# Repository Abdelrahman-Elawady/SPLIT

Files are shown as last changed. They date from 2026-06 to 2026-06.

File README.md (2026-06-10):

<div align="center">
  
# 🤖 Project S.P.L.I.T.
**Snapping Pendulums Literally In Two**






*A highly advanced, self-balancing robotic swarm architecture utilizing distributed Dual-MCU processing, cascaded PID control, and computer vision for high-density indoor micro-logistics.*

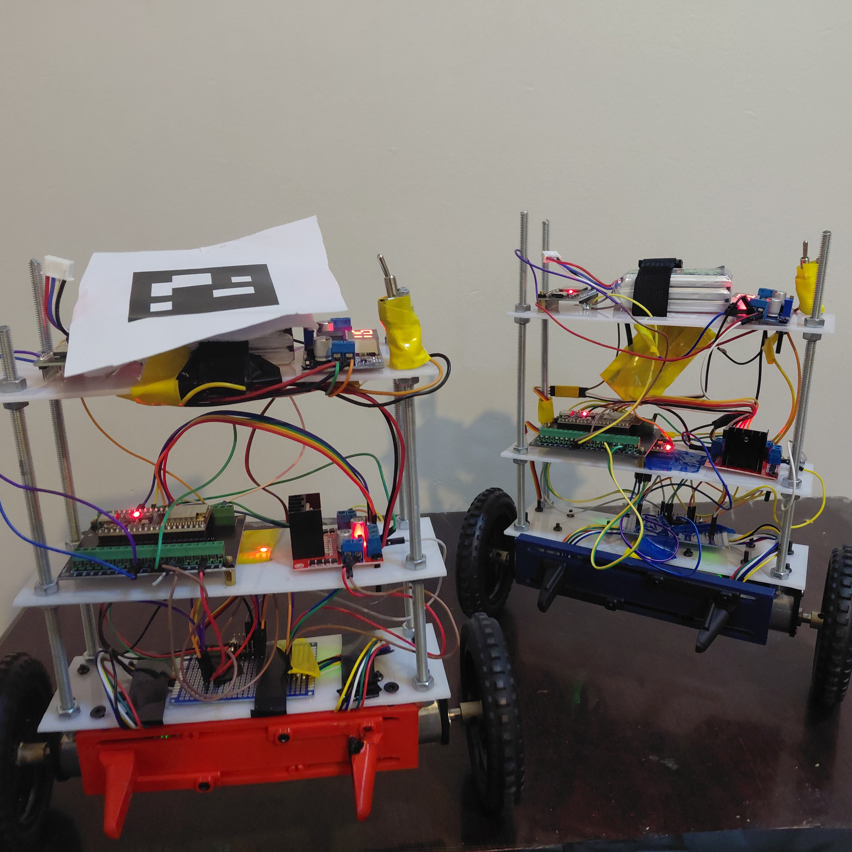
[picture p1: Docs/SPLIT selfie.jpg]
S.P.L.I.T. Swarm


**[🎥 Watch the Project Trailer on YouTube](https://youtu.be/ys7Rda4Vqj8?si=qLUs55d14E2go74t)**

</div>

---

## 📖 Table of Contents
1. [About the Project](#-about-the-project)
2. [Swarm Demonstration](#-swarm-demonstration)
3. [Distributed Hardware Architecture](#-distributed-hardware-architecture-dual-mcu)
4. [Control Theory & Physics](#-control-theory--physics)
5. [Real-Time Telemetry Dashboard](#-real-time-telemetry-dashboard)
6. [Computer Vision & Teleoperation](#-computer-vision--teleoperation)
7. [Repository Structure](#-repository-structure)

---

## 🚀 About the Project

Modern warehouse facilities face a critical spatial bottleneck: traditional four-wheeled logistics robots require massive floor space and wide aisles to maneuver safely. 

**Project S.P.L.I.T.** is a self-balancing robotic swarm developed at the **University of Prince Mugrin (UPM)**. By navigating exclusively on two wheels as inverted pendulums, these robots drastically reduce their physical footprint. This allows industrial facilities to narrow their aisles and maximize high-density storage without sacrificing payload capacity.

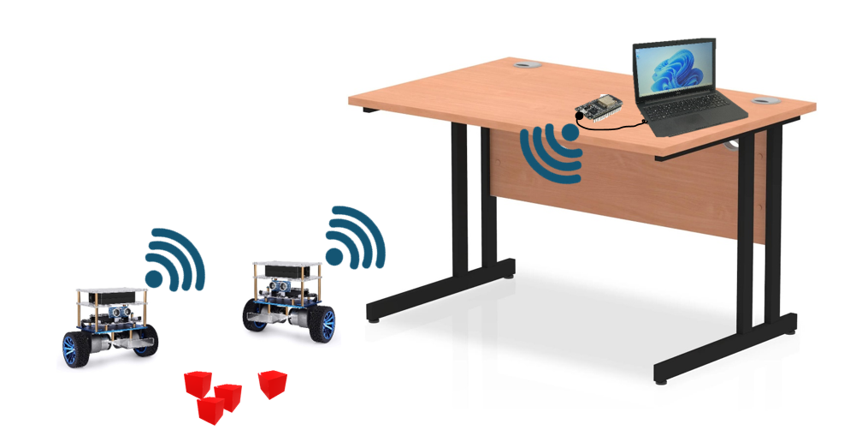
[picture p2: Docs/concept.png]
Concept Architecture


---

## 🤖 Swarm Demonstration

*Click the image below to watch the physical robots balancing and maneuvering together:*

Robots Balancing Demo (https://youtu.be/6psPYHQWWL8?si=IynwXiYcK6a_89gq)

---

## 🧠 Distributed Hardware Architecture (Dual-MCU)

One of the most fatal flaws in DIY robotics is asking a single microcontroller to handle both high-speed physics calculations and heavy wireless network routing. Pausing for just a few milliseconds to process a Wi-Fi packet causes a balancing robot to violently crash.

We solved this by establishing a **Distributed Dual-MCU Architecture** governed by a central Bridge router:

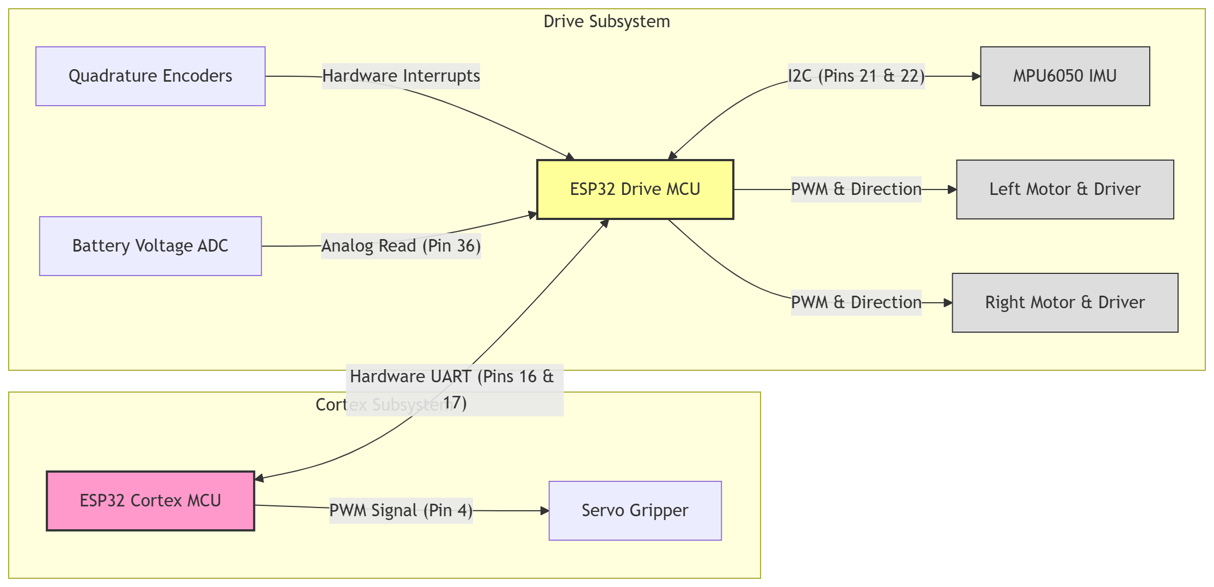
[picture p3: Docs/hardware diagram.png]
Hardware Topology


1. **The Drive MCU (Physics Engine):** An ESP32 dedicated entirely to survival. Its Wi-Fi radio is physically disabled. It reads the MPU6050 IMU, tracks the quadrature encoders, and executes the 200 Hz balancing math.
2. **The Cortex MCU (The Brain):** A secondary ESP32 that handles payload actuation (Servo Gripper) and acts as the communications relay. It communicates with the Drive MCU via a 500,000 baud hardware UART connection, utilizing a custom `0xAA 0xAA` header packet to prevent data corruption.
3. **The Bridge MCU (The Router):** A central hub plugged into the control station. It hosts a local Wi-Fi Access Point and Web Server, routing traffic to the robot swarm via the ultra-low-latency ESP-NOW protocol.

---

## ⚖️ Control Theory & Physics

Keeping a two-wheeled robot upright requires absolute mathematical precision. To maintain equilibrium, we implemented a **Cascaded PID (Proportional-Integral-Derivative) Controller**.

The system relies on three simultaneous control loops working in harmony:
* **Inner Angle Loop (200 Hz):** Calculates the difference between the robot's current tilt and the target angle, outputting raw PWM signals to the motor drivers to prevent falling.
* **Outer Speed/Position Loop (10 Hz):** Reads high-resolution wheel encoders. If the robot drifts, it calculates a position error and shifts the *Target Angle* of the inner loop, causing the robot to lean and drive to the correct location.
* **Yaw Loop (200 Hz):** Reads the Z-axis gyroscope to ensure motors spin in perfect synchronization.

> **Note on Sensor Fusion:** We bypassed the MPU6050's built-in DMP to avoid processing delays. Instead, we pull raw accelerometer and gyroscope data via a 400kHz I2C bus and run it through our own **Kalman Filter** to neutralize motor vibrations and correct gyroscope drift.

---

## 📊 Real-Time Telemetry Dashboard

Tuning a cascaded PID controller requires extreme patience. To solve this, we built a comprehensive telemetry dashboard hosted entirely on the Bridge MCU's SPIFFS memory.

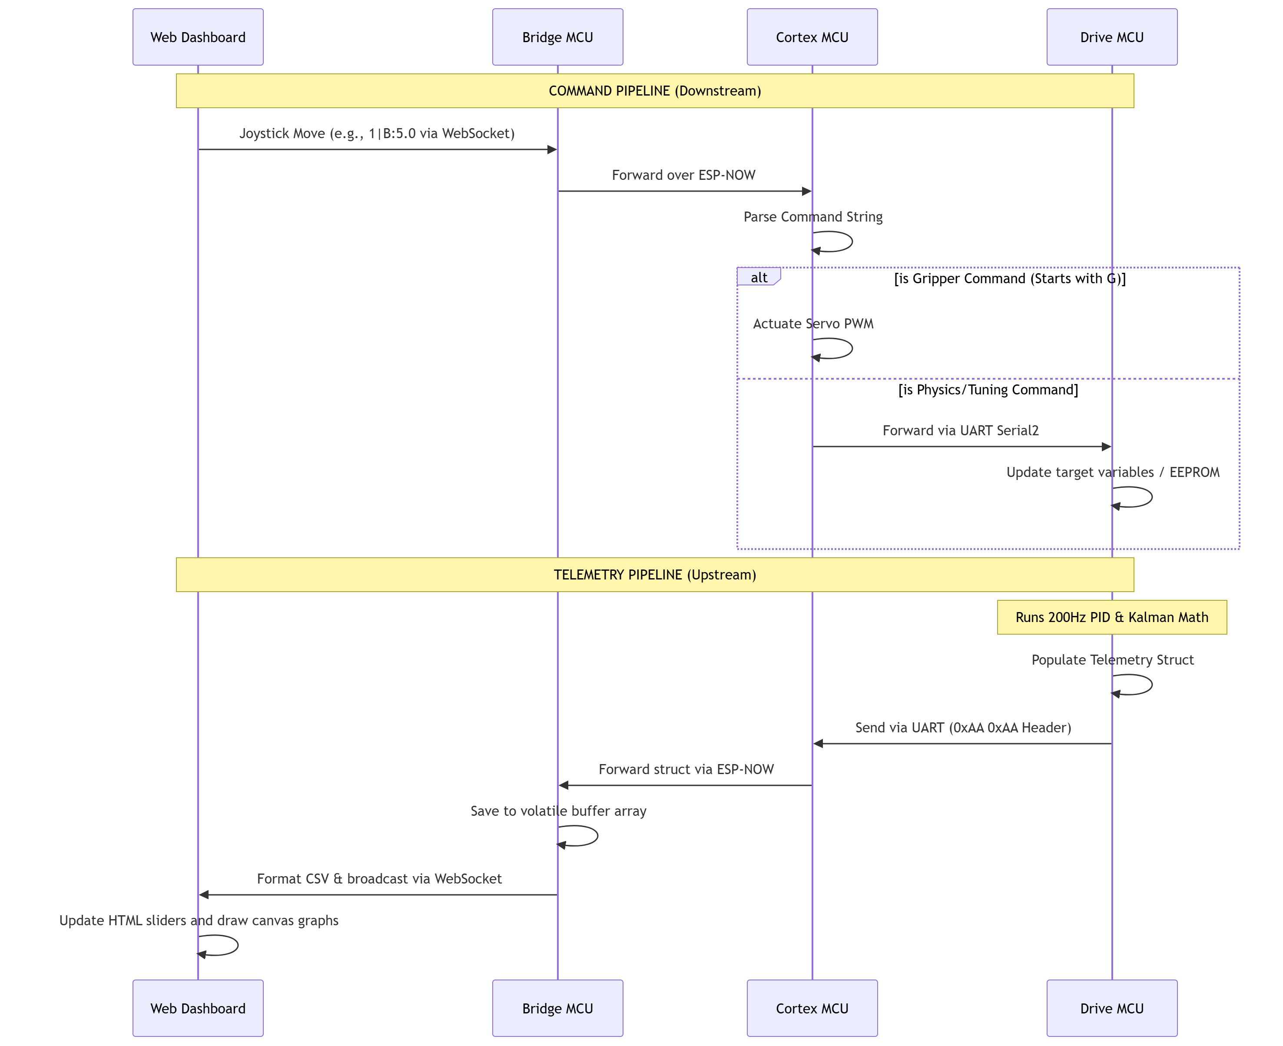
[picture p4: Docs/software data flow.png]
Software Data Flow


*Click the image below to watch the live Telemetry Dashboard and auto-scaling graphs in action:*

Telemetry Dashboard Video (https://youtu.be/Q8Spe14jKmc?si=H875WhGmwUKity3f)

---

## 👁️ Computer Vision & Teleoperation

Because onboard cameras would shift the center of mass, we offloaded vision processing to an external global system running on a laptop (The "Eye in the Sky").

* **ArUco Pathfinding:** A Python script utilizing OpenCV detects distinct ArUco markers on each robot. It calculates the robot's exact X/Y coordinates and Yaw (heading direction), generating forward throttle and steering vectors to route the robot to its destination.
* **Hand Gesture Control:** Integrated **MediaPipe Hand Tracking** maps 21 3D landmarks of a human hand. The system translates physical hand gestures into direct kinematic commands, allowing operators to direct the swarm seamlessly.

*Click the image below to watch the autonomous Computer Vision pathfinding in action:*

Computer Vision Navigation Video (https://youtu.be/ys7Rda4Vqj8?si=IiXEYzNkCtTVPJel)

---

## 📁 Repository Structure

```text
SPLIT-Robotics-Swarm/
├── Firmware/                                  # Embedded C++ code for the ESP32s
│   ├── bridge-controller/                     # esp32 bridge code wifi and esp32 now
│   │   ├── data/                              # SPIFFS Web Files (HTML/CSS/JS)
│   ├── cortex-controller/                     # Robot 1: ESP-NOW relay & Servo
│   ├── cortex-controller-B/                   # Robot 2: ESP-NOW relay & Servo
│   ├── drive-controller/                      # Robot 1: 200Hz PID & Kalman math
│   └── drive-controller-B/                    # Robot 2: 200Hz PID & Kalman math
│
├── Software/                                  # Off-board applications
│   └── Computer Vision/           
│       ├── hand_gesture.py                    # MediaPipe hand gesture script
│       ├── robot_aruco_guard.py               # ArUco tracking and vector math
│       └── requirements.txt                   # Python dependencies
│
├── Hardware/                                  # Physical design references
│   ├── circuit diagram concept.jpeg           # System wiring diagram
│   └── (pinout reference images)              # ESP32, L298N, and Motor pinouts
│
├── Testing/                                   # Isolated step-by-step calibration scripts
│   ├── Testing-encoders/             
│   ├── Testing-IMU-calibration/               # Script to find MPU6050 offsets
│   ├── Testing-motors/
│   ├── Testing-MAC-address/
│   ├── self-balancing-1-loop/                 # Incremental PID testing
│   ├── self-balancing-2-loops/
│   ├── self-balancing-3-loops/
│   └── (other component tests)
│
└── Docs/                                      # Images, posters, and documentation

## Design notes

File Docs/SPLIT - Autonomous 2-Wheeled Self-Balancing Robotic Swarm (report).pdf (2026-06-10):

P a g e | 1

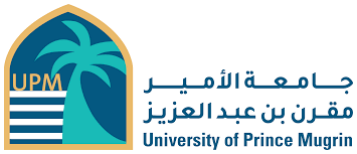
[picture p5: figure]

## SPLIT (Snapping Pendulums Literally In Two): Autonomous 2-

## Wheeled Self-Balancing Robotic Swarm

## College of Engineering

## Electrical Engineering

Course IDs and Names:

### - EE 461 Control Systems Analysis - EE 312 Electromagnetic Waves - EE 326 Microprocessors & Microcontrollers

Course Instructors:

### - Dr. Alhussain Almarhabi - Dr. Noura Alhazmi - Eng. Basel Jouda

## Date: 10 June 2026

IDs | Names
4413746 | Abdelrahman Elawady
4410215 | Ibrahim Albarbari
4311147 | Ghazi Alhartani
4410606 | Hassan Nasr

Abstract

Modern industrial logistics faces severe spatial bottlenecks caused by the wide turning radii of

traditional four-wheeled rovers. To address this complex engineering problem, this paper presents

the design, mathematical modeling, and control of an Autonomous 2-Wheeled Self-Balancing

Robotic Swarm (Project S.P.L.I.T.). By utilizing an inverted pendulum architecture, the physical

footprint of the robot is drastically reduced, trading horizontal space for vertical efficiency. The

system utilizes a distributed dual-microcontroller architecture to decouple high-speed physics

calculations from wireless network routing. Dynamic stability is achieved through a 200 Hz and

10Hz cascaded Proportional-Integral-Derivative (PID) controller, complemented by a Kalman

filter for sensor fusion of MPU6050 accelerometer and gyroscope data. Furthermore, the system

integrates computer vision via OpenCV and MediaPipe for autonomous ArUco marker pathfinding

and hand-gesture teleoperation. Experimental validation confirms that the proposed distributed

architecture successfully mitigates network-induced processing delays, achieving near-zero pitch

error and robust dynamic stability. The results demonstrate a highly efficient, scalable, and

kinematically viable solution for automated high-density indoor micro-logistics..

Keywords: Two-Wheeled Inverted Pendulum; Cascaded PID Control, Sensor Fusion; Distributed

Architecture; Computer Vision; Autonomous Swarm; Kalman Filter; Lagrangian Mechanics.

Table of Contents

### I. Introduction

A. Background and Motivation

In the past decade, mobile robots have stepped out of the military and industrial settings, and

entered civilian and personal spaces [1]. As industries move toward complete automation,

warehouse facilities encounter critical limitations regarding floor space and navigable pathways.

Traditional logistics robots operate on four wheels, requiring wide aisles to maneuver safely and

transport payloads. A proposed solution to this spatial inefficiency is the implementation of two-

wheeled self-balancing robots, which are mechanically similar to the inverted pendulum—an

important testbed in control education and research [1]. By balancing vertically on a single primary

axis, these robots can turn with a zero-degree radius and navigate remarkably narrow corridors.

However, the inverted pendulum is a highly unstable and non-linear system [2]. It is one of the

most complex systems to control in engineering due to its non-linear dynamics, making it an

appropriate test platform for the design and development of advanced control systems [2]. The

physical assembly and overall hardware architecture of the proposed S.P.L.I.T. robot, designed to

address these challenges, are illustrated in Fig. 1.

a)

b)

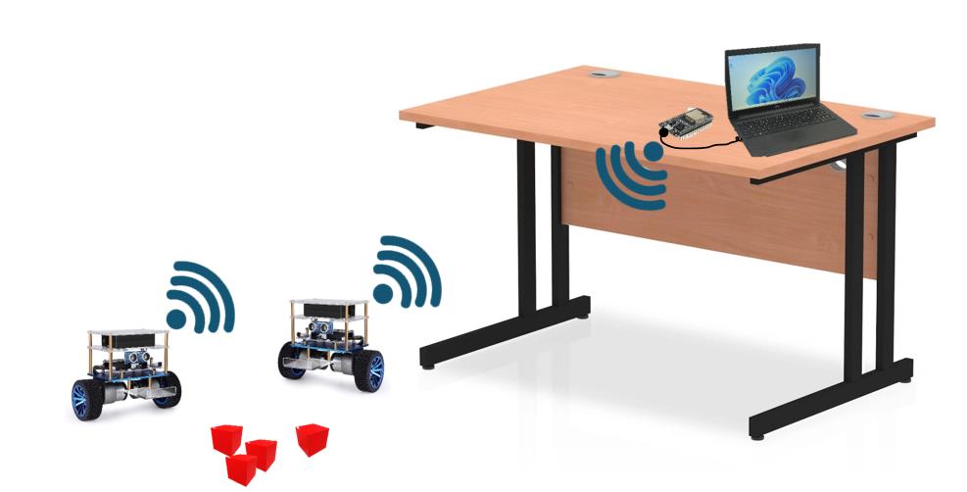
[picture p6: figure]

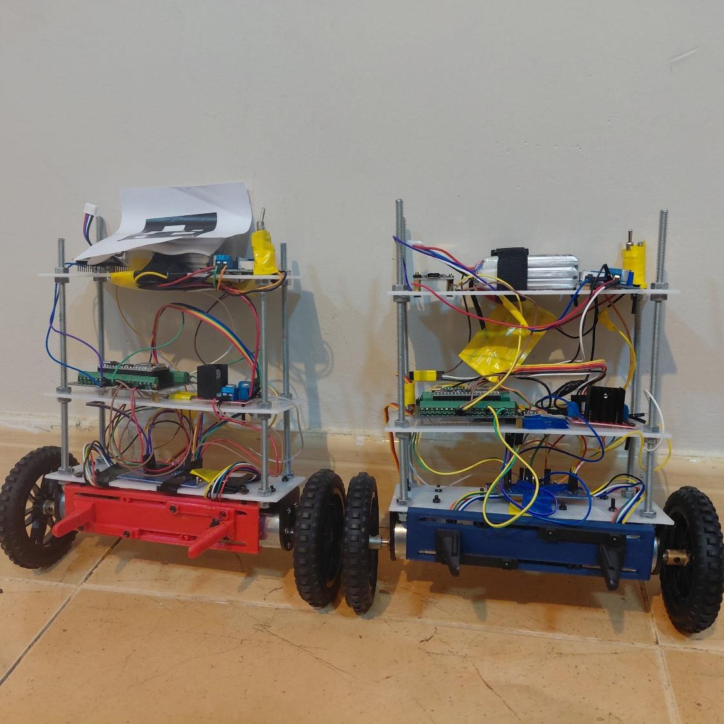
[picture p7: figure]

Fig. 1: Overall System architecture (a) and physical assembly (b) of the S.P.L.I.T. autonomous two-wheeled self-balancing robot.

B. Problem Formulation and Mathematical Modeling

To successfully engineer a self-balancing swarm, fundamental principles of science and

mathematics must be applied to formulate the physical problem. A two-wheel self-balancing robot

is fundamentally an inverted pendulum on a cart [3]. Because its center of mass sits above its pivot

point (the wheel axle), the system is naturally unstable and nonlinear. If left alone, gravity will

immediately pull it to the ground [3]. There are generally two kinds of mathematical models used

for the inverted pendulum control system: the Newton-Euler method and the Lagrange method [4].

Using the Newton-Euler approach, the upright car body can be regarded as an inverted pendulum

on the left and right moving platforms, as depicted in the free-body diagram in Fig. 2 [4]. When

the inverted pendulum is placed out of balance, the recovery force is in the same direction as the displacement, causing it to accelerate away from the vertical position until it falls [4]. To balance

the pendulum, extra force and speed must be added so that the restoring force is in the opposite

direction of the wheel displacement [4]. For a robot of mass m and tilt angle θ, the restoring force

F can be defined using trigonometric relationships and linearized for small angles as shown in the

following equation [4]:

F = mg sin θ − ma cos θ ≈ mgθ − k1θ

Alternatively, applying Lagrangian mechanics provides an elegant, energy-based approach to

derive the dynamic equations of motion [3]. The Lagrangian ℒ is defined as the difference between

the total kinetic energy Ek and the potential energy Ep of the system [3]. Defining zero potential

energy at the upright position, the potential energy is Ep = mgL(cos θ − 1) [3]. By applying the

Euler-Lagrange equation to the generalized coordinates for the tilt angle θ and linear displacement

x, the nonlinear equations of motion are extracted [3]. Solving these partial derivatives yields

equations that are linearized around the vertical operating point (θ ≈ 0), allowing engineers to

apply standard control strategies to keep the robot upright [3].

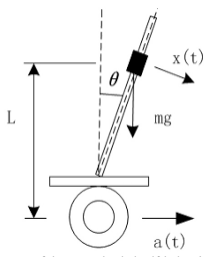
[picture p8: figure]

Fig. 2: Schematic and free-body diagram of the two-wheeled self-balancing robot defining the center of mass, wheel radius, and tilt angle θ [4].
A. Project Objectives

The main focus of this research is to develop an efficient controller required to enable the robot to

act in real time and test its performance by the vertical balance, position, and control signal capabilities. To achieve this, the project establishes a custom distributed hardware architecture.

One of the most fatal flaws in DIY robotics is asking a single microcontroller to handle both high-

speed physics calculations and heavy wireless network routing, as pausing for just a few

milliseconds to process a Wi-Fi packet causes a balancing robot to violently crash. Therefore, the

primary objective is to decouple the processing load using dedicated microcontrollers for the

physics engine and the network telemetry. The secondary objective is to implement a high-

frequency cascaded PID controller fused with a Kalman filter to process MPU6050 gyroscope and

accelerometer data, achieving near-zero pitch error. The final objective is to integrate a global

computer vision system that runs OpenCV and MediaPipe algorithms to direct the swarm

autonomously, bypassing the limitations of traditional remote controllers.

### II. Mathematical Modeling & Control Systems

A. System Dynamics and Kinematics

The development of a robust self-balancing robot fundamentally relies on accurate mathematical

modeling to capture its highly nonlinear and coupled dynamics. The Lagrange method provides a

rigorous framework for building the kinetic equations by evaluating the kinetic, potential, and

dissipated energy of the system. Defining zero potential energy at the upright position, the potential

energy Ep of the robot is defined as:

| Ep = mgL(cos θ − 1)

The kinetic energy Ek of the system, factoring in the moment of inertia and mass of the wheels

and body, is expressed as:

| Ek =
| 1
| 2 (Iw + mwR 2 + mR
| 2 )φ̇ 2 + mRL cos θ φ̇θ̇ +

1
2

(I + mL

2

)θ̇²

The Lagrangian ℒ is written as the difference between the kinetic energy and the potential energy:

| ℒ = Ek − Ep

By applying the Euler-Lagrange equation to the generalized coordinates, the dynamic equations

of motion are derived. For the linear displacement coordinate, the equation yields the generalized

force μ:

d
dt (

∂ℒ
∂φ̇

) −

∂ℒ
∂φ = (Iw + mwR

2 + mR

2

)φ̈+ mRL cos θ θ̈− mRL sin θ θ̇² = μ

Similarly, for the angular tilt coordinate, the equation yields the generalized torque $\chi$:

d
dt (

∂ℒ
∂θ̇

) −

∂ℒ
∂θ = (I + mL

2

)θ̈+ mRL cos θ φ̈− mRL sin θ = χ

Alternatively, the Newton-Euler method analyzes the forces and torques acting directly on the

chassis and the individual wheels. By separating the wheels from the pendulum, the right and left

wheel force equations can be combined to form the translational dynamic equation:

2 (Mw +

Iω
R²

) ẍ=

CR + CL
R

− (HR + HL

)

Once these nonlinear dynamics are established, they are linearized around the equilibrium point

(θ ≈ 0) to map the system into a state-space representation, allowing for the design of optimal

controllers.

B. Linear Quadratic Regulator (LQR) and Proportional-Integral-Derivative (PID)

Control

To achieve dynamic balance within a specific angle range, a combination of Proportional-Integral-

Derivative (PID) and Linear Quadratic Regulator (LQR) control methodologies is highly effective.

The PID controller is the most widely adopted linear control strategy, calculating the control signal

u(t) based on the error signal e(t), its integral, and its derivative. The continuous-time ideal PID

equation is expressed as:

u(t) = Kpe(t) + Ki ∫ e

t

0

(τ)dτ + Kd

de(t)
dt

Where Kp, Ki

, and Kd represent the proportional, integral, and derivative gains, respectively.

However, because the control algorithm is executed on a digital microcontroller, the continuous

equation must be discretized. To improve computational efficiency and system reliability, an

incremental digital PID algorithm is utilized. The incremental output Δu(k) at sampling time k is

derived as:

Δu(k) = KP(e(k) − e(k − 1)) + KIe(k) + KD(e(k) − 2e(k − 1) + e(k − 2))

While classic PID control does not rely on a linearized model and offers strong robustness, LQR

provides an optimal control strategy that seeks to minimize a quadratic cost function J to reach a

steady state. This cost function is defined by the integral of the state vector X and control input u,

penalized by the symmetric positive-definite weight matrices Q and R:

J = ∫ (X
TQX + u

TRu)

∞

0

dt

The optimal control law is given by u = −Kx, where the optimal state feedback matrix K is

determined by solving the continuous-time algebraic Riccati equation:

PA + A

TP + Q − PBR

−1B

TP = 0

K = R

−1B

TP

While LQR delivers excellent control near the balance point, its effectiveness diminishes rapidly

as the robot tilts further away from equilibrium. In contrast, classic PID control does not rely on a

linearized model and offers strong robustness, making it capable of rapid recovery when the robot

experiences larger deviations. A hybrid controller leverages the strengths of both by defining a

controlling factor that limits the outputs depending on the tilt angle, thereby relying heavily on

LQR for fine stabilization and invoking PID when the angle exceeds the linear constraints.

Furthermore, selecting the Q and R matrices for the LQR controller traditionally depends on trial

and error, which introduces subjectivity and impacts control quality. Implementing a Particle

Swarm Optimization (PSO) algorithm overcomes this limitation. The PSO algorithm initializes a

swarm of particles representing the state variables and updates their velocity v and position x

across iterations using the following evolution formulas:

vid

k+1 = wvid

k + c1∂(pid

k − xid

k
) + c2β(pgd

k − xid

k
)

xid

k+1
(t + 1) = xid

k
(t) + vid

k
(t)

By utilizing this iterative evolution to search for the global optimal solution for the Q and R

matrices, the optimized LQR approach yields faster response speeds, reduced overshoot, and zero

steady-state error.

C. Artificial Intelligence and Reinforcement Learning

As computational capabilities have advanced, artificial intelligence has emerged as a

transformative methodology for managing the underactuated and nonlinear dynamics of two-

wheeled self-balancing robots. Reinforcement learning focuses on training an agent to learn

optimal control policies strictly through interaction with its environment. This model-free

paradigm is particularly well-suited for these complex systems, as it circumvents the strict

requirement for precise mathematical modeling. Through continuous trial and error, the robot

autonomously acquires balancing and navigation behaviors that adapt to varying operational

conditions. Algorithms such as Q-learning and Deep Q-Networks have successfully enabled these

highly adaptive responses. Moreover, reinforcement learning can be seamlessly integrated with

classical techniques to create hybrid intelligent frameworks. Reinforcement learning policies are

often utilized to automatically tune PID parameters in real-time or to solve LQR problems without

relying on exact system parameters. These advanced strategies offer significant advantages in

learning ability and generalization, ensuring robust stability even in unstructured and unpredictable

industrial environments.

### III. Microcontroller Architecture and Hardware Design

A. Hardware Standards and Protocols

Specify relevant industry standards or recommended practices that guide the detailed design to

ensure the safety, reliability, and performance of the system. The internal hardware architecture of

the robot heavily relies on the Inter-Integrated Circuit (I2C) communication protocol for

interfacing the IMU sensor with the microcontroller, following the manufacturer recommended

practices for a 400 kHz fast-mode bus. For inter-microcontroller communication, the Universal

Asynchronous Receiver-Transmitter (UART) standard is utilized. Externally, the swarm network

topology operates on the IEEE 802.11 standard to host the local WebSockets dashboard, while

utilizing the ultra-low-latency ESP-NOW protocol for machine-to-machine command routing.

Furthermore, the embedded firmware is developed in C++ adhering to standard object-oriented

programming principles to ensure memory safety and prevent buffer overflows during real-time

execution.

B. Distributed Dual-MCU Paradigm

A critical point of failure in standalone autonomous robotics is overburdening a single

microcontroller with both high-speed physics calculations and heavy wireless network routing.

Pausing the primary processor for just a few milliseconds to process a Wi-Fi packet causes a

balancing robot to miss a sensor reading and violently crash. To resolve this, the system decouples

the processing load using a distributed Dual-MCU architecture on each robot, overseen by a global

Bridge router.

1. The Drive MCU: This primary ESP32 serves exclusively as the physics engine. Its Wi-Fi

radio is completely disabled via software to free up all hardware interrupts. It reads the

MPU6050 IMU, tracks the motor quadrature encoders, and executes the 200 Hz cascaded

PID balancing mathematics.

2. The Cortex MCU: This secondary ESP32 operates as the cognitive brain of the individual

robot. It handles payload actuation through the servo grippers and acts as the

communications relay, processing all incoming ESP-NOW packets and forwarding them

to the Drive MCU.

3. The Bridge MCU: A stationary central hub plugged into the operator control station. It

hosts a local Wi-Fi Access Point and an asynchronous Web Server via SPIFFS, routing

traffic to the entire robot swarm.

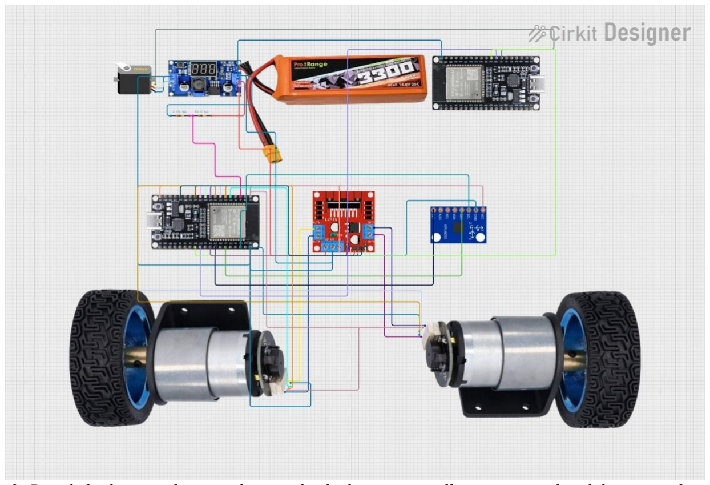
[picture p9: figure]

Fig. 3: Detailed schematic diagram showing the dual-microcontroller setup, peripheral devices, and sensor connections.

C. Detailed Design and Bill of Materials

The hardware schematic (figure 3) provides a clear layout of the microcontroller pin connections,

sensors, and actuators. The Drive MCU interfaces with the L298N motor driver using high-

resolution 5000 Hz PWM signals, ensuring smooth motor acceleration. The MPU6050 sensor is

connected via the standard I2C pins (GPIO 21 and 22), while the quadrature encoders trigger

hardware interrupts to track wheel positioning.

The complete Bill of Materials (BOM) listing the components used alongside their specifications

is detailed in Table I.

TABLE I

BILL OF MATERIALS (BOM)

Component | Specification | Functionality

Microcontroller

ESP32 Dual-Core (240

MHz)

Handles | physics | calculations | and

network routing.

IMU Sensor | MPU6050 (6-Axis)

Measures raw acceleration and angular

velocity.

Motor Driver | L298N Dual H-Bridge

Regulates voltage and direction for the

DC motors.

Actuators

12V DC Gear Motors

(333 RPM)

Provides locomotion and balancing

torque.

Feedback

Magnetic Quadrature

Encoders

Tracks precise wheel displacement and

speed.

Payload

Actuator

MG995 High-Torque

Servo

Drives the 3D-printed rack and pinion

gripper mechanism.

Power Supply

11.1V 1500mAh LiPo

Battery

Provides high-discharge current for the

motors and MCUs.

D. System Flow and Communication

To effectively communicate the design intent and functionality, the software architecture (figure

4) is structured into two parallel pipelines: a downstream command pipeline and an upstream

telemetry pipeline. The Cortex MCU and the Drive MCU communicate over a highly optimized

500,000 baud hardware UART Serial connection. To prevent data corruption during the high-speed transfer of floating-point variables, a custom packet structure is implemented utilizing a

0xAA 0xAA byte header.

When an operator inputs a command via the WebSockets dashboard, the Bridge MCU formats the

string and broadcasts it via ESP-NOW. The Cortex MCU receives this payload, determines if it is

a mechanical gripper command or a physics tuning parameter, and either actuates the servo directly

or passes the variables down the UART pipeline to the Drive MCU. Conversely, the Drive MCU

populates a telemetry structure with its current pitch angle, motor PWM output, and PID error

terms at 200 Hz, sending it upstream to the dashboard for live graphing.

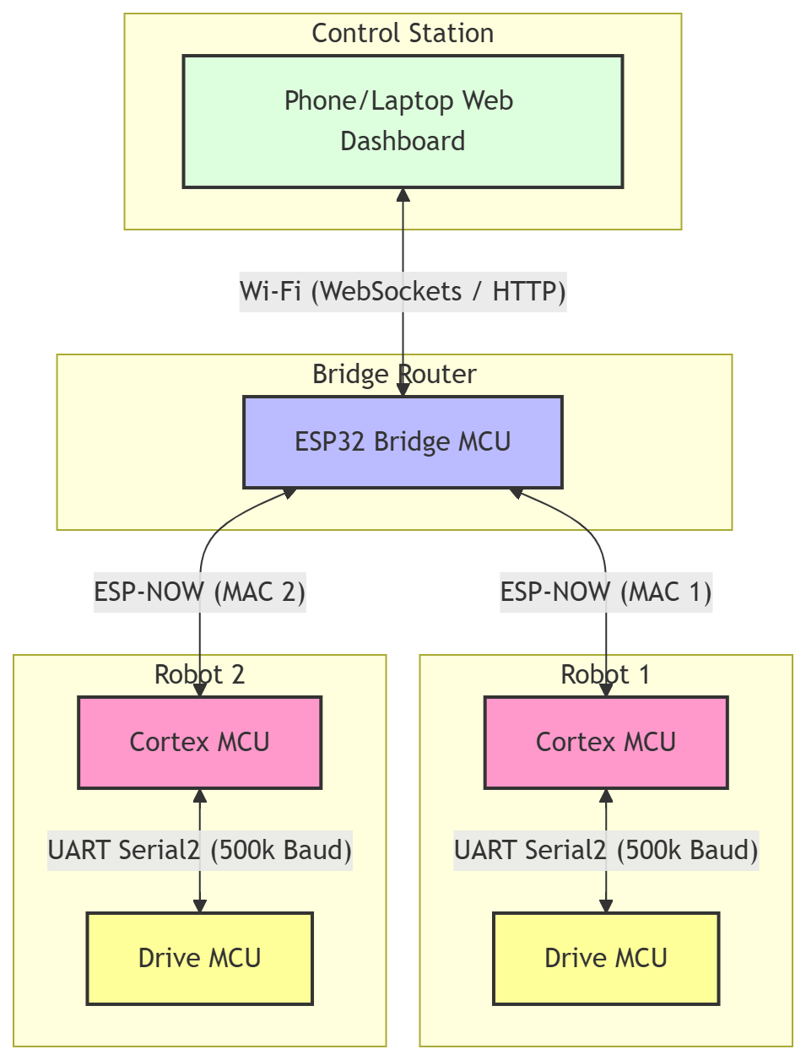
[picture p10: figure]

Fig. 4: Flowchart depicting the program flow and communication pipelines between the Web Dashboard, Bridge MCU, Cortex MCU, and Drive MCU.

### IV. Electromagnetic & RF Communication Analysis

A. 2.4 GHz Electromagnetic Wave Properties

The distributed swarm architecture relies entirely on the rapid transmission of telemetry and

control variables. The ESP32 microcontrollers communicate utilizing the ESP-NOW protocol,

which operates on the 2.4 GHz Industrial, Scientific, and Medical (ISM) radio band.

Understanding the electromagnetic wave propagation of this protocol is critical for ensuring that

the robots do not lose connection and crash while navigating a warehouse. At a frequency of f =

2.4 GHz, the wavelength λ of the RF signal is calculated using the speed of light c:

λ =

c
f

=

3 × 10⁸
2.4 × 10⁹

≈ 0.125 meters

In an ideal free-space environment, electromagnetic waves radiate uniformly spherically. The

Received Signal Strength Indicator (RSSI), denoted as Prx, is determined by the transmit power

Ptx minus the Path Loss (PL). However, an industrial warehouse is a complex multipath

environment filled with metallic storage racks. Electromagnetic waves at 12.5 cm are highly

susceptible to reflection, scattering, and severe attenuation when passing through highly

conductive metallic obstacles. To accurately predict the signal strength available to the moving

pendulum robots, a Log-Distance Path Loss model is applied:

PL(d) = PL(d0

) + 10n log10 (

d
d0

) + Xσ

Where PL(d0

) is the reference path loss at 1 meter, n is the path loss exponent representing the

indoor obstruction severity (typically n = 3.0 for industrial buildings), d is the distance from the

Bridge router, and Xσ represents the shadow fading attenuation caused by physical metallic

structures.

B. MATLAB Simulation and Interpretation of Results

To validate the reliability of the ESP-NOW communication network, a spatial electromagnetic

wave simulation was performed using MATLAB, results shown in figure 5. The simulation models a 30 by 30 meter warehouse environment with the Bridge MCU transmitting at a standard 20 dBm.

A spatial grid was generated to map the calculatedPrx utilizing the aforementioned Log-Distance

model. To accurately represent real-world industrial conditions, two dense metallic storage racks

were introduced into the spatial matrix, applying a 15 dB shadow fading attenuation penalty Xσ to

the electromagnetic waves passing through those coordinates.

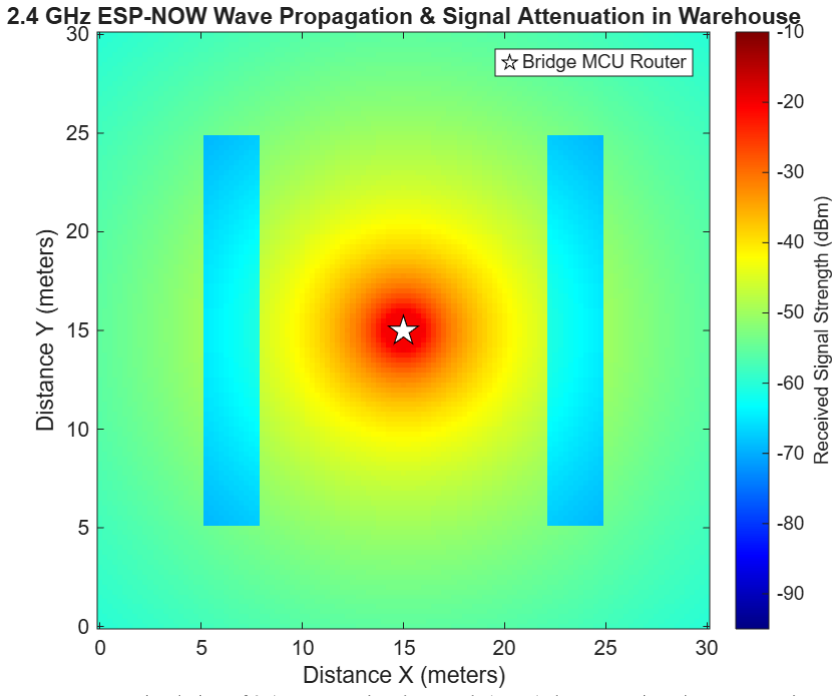
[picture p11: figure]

Fig. 5: MATLAB simulation of 2.4 GHz RF signal strength (RSSI) demonstrating electromagnetic wave attenuation caused by free-space path loss and metallic warehouse racks.

The simulation results provide critical insights into the swarm communication topology. As

observed in the generated heatmap, the signal strength decays logarithmically from the central

Bridge MCU. The most prominent feature of the simulation is the severe signal degradation

directly behind the metallic racks, dropping into the blue visual spectrum. However, the ESP32

transceiver maintains a minimum receiver sensitivity of approximately -85 dBm. The simulation

verifies that despite the multipath fading and metallic attenuation, the RSSI across the entire 900

square-meter facility remains above -80 dBm. This interpretation confirms that the 2.4 GHz ESP-

NOW protocol is electromagnetically robust enough to sustain the 200 Hz telemetry pipeline

without packet loss, ensuring the robots maintain dynamic equilibrium regardless of their physical

location in the warehouse.

### V. Wireless Telemetry and Web Dashboard Control

A. Distributed Network Topology and SoftAP

To facilitate seamless communication between the operator and the robotic swarm, the central

Bridge MCU is configured as a Software Access Point (SoftAP), broadcasting a localized Wi-Fi

network (typically at 192.168.4.1). This central router hosts a fully asynchronous web server stored

in its SPIFFS (Serial Peripheral Interface Flash File System) memory. By offloading the web

hosting and HTTP request handling to this stationary Bridge MCU, the individual moving robots

are entirely shielded from network-induced latency spikes, allowing their internal Drive MCUs to

maintain an uninterrupted 200 Hz physics loop.

B. HTTP REST API and WebSockets

The swarm architecture utilizes two distinct communication protocols based on the required data

speed. For discrete kinematic commands generated by the Python computer vision scripts, the

Bridge MCU exposes an HTTP REST API. The vision system transmits commands via standard

GET requests parameterized with the target robot ID and movement state (e.g.,

http://192.168.4.1/cmd?robot=1&move=FORWARD). The Bridge MCU parses this HTTP request and

instantly relays it to the specific robot via the low-latency ESP-NOW protocol. The mechanism is

shown in figure 6.

Conversely, tuning the cascaded PID controller requires high-speed, continuous data streaming.

For this, a WebSockets connection is established between the web dashboard and the Bridge MCU.

The robots transmit their internal pitch angles, motor PWM outputs, and error terms back to the

Bridge, which broadcasts the telemetry over WebSockets to the HTML/JS dashboard. This allows

engineers to visualize real-time, auto-scaling performance graphs at 20 frames per second and

dynamically adjust Kp, Ki

, and Kd gains on the fly.

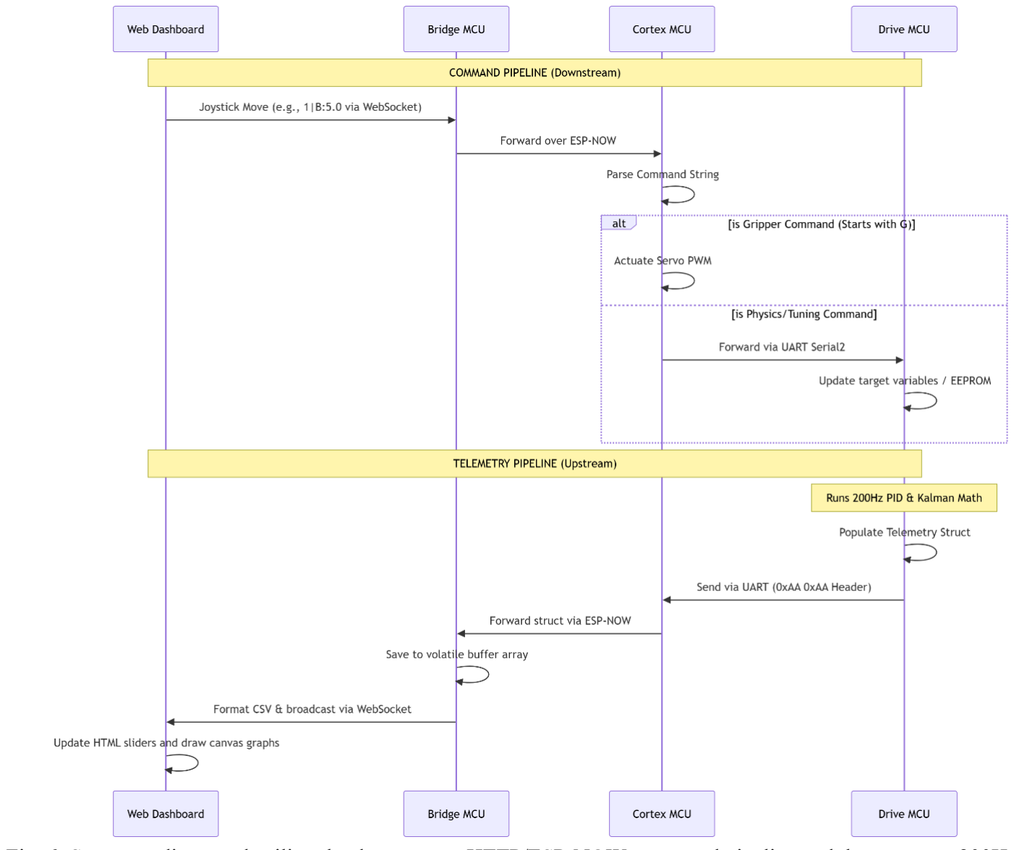
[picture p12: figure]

Fig. 6: Sequence diagram detailing the downstream HTTP/ESP-NOW command pipeline and the upstream 200Hz WebSocket telemetry flow.

### VI. Computer Vision & Global Teleoperation

A. ArUco Marker Pathfinding and Spatial Mathematics

To enable autonomous navigation without burdening the onboard microcontrollers, spatial

processing is offloaded to a Python-based global vision system using the OpenCV library. Each

robot features a unique 5x5 fiducial marker from the DICT_5X5_250 ArUco dictionary. The

algorithm detects the four corners of the marker to compute the robot's center coordinate (xc
, yc

)

and its directional heading vector ℎ⃗ . The heading is mathematically derived by subtracting the

center point from the midpoint of the marker's top two corners.

To navigate the robot along a pre-programmed path of waypoints (see figure 7), the system

calculates a desired trajectory vector v pointing from the robot's center to the target waypoint. To

determine the necessary rotational command, the algorithm calculates the angular error θerror

between the robot's current heading ℎ⃗ and the desired vector v . This is computed efficiently using

the dot product and cross product of the normalized vectors:

ℎ⃗ ⋅ v = ℎxvx + ℎyvy

ℎ⃗ × v = ℎxvy − ℎyvx

θerror = arctan 2 (ℎ⃗ × v , ℎ⃗ ⋅ v )

A 45-degree deadzone is implemented to prevent control jitter. If |θerror| ≤ 45∘
, an HTTP GET

request for "FORWARD" is transmitted. If the error exceeds these bounds, "LEFT" or "RIGHT"

commands are issued. Furthermore, the algorithm actively superimposes collision vectors and

edge-margin boundaries, overriding the waypoint vector to steer the robots away from physical

boundaries and prevent multi-agent collisions.

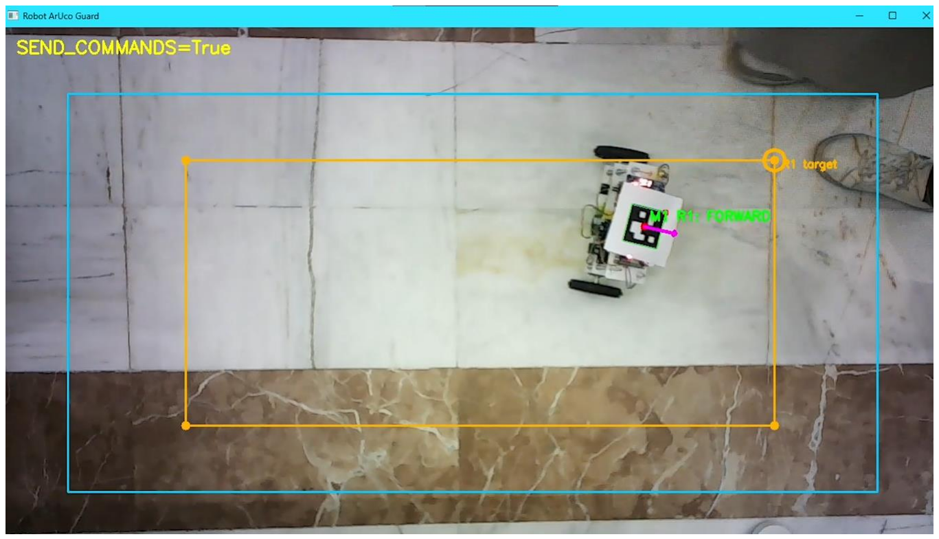
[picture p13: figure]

Fig. 7: OpenCV pathfinding interface calculating heading vectors and distance parameters to autonomously route the swarm through designated waypoints.

B. Kinematic Hand-Gesture Teleoperation

In addition to autonomous waypoint navigation, the system integrates a teleoperation module

utilizing the MediaPipe machine learning framework. The algorithm extracts 21 3D skeletal

landmarks from the operator's hand in real time. Rather than relying on complex gesture

classification models, the control logic is highly optimized using a geometric y-coordinate

comparison between the tips (landmarks 8, 12, 16, 20) and the Proximal Interphalangeal (PIP)

joints (landmarks 6, 10, 14, 18).

Because image pixel coordinates originate from the top-left, a finger is classified as "raised" if the

y-coordinate of its tip is less than the y-coordinate of its corresponding PIP joint. The system sums

the number of raised fingers to dictate the kinematic state: one finger commands "FORWARD",

two fingers command "BACKWARD", three fingers command "RIGHT", and four fingers

command "LEFT". This state is sampled, rate-limited to a 0.2-second period to prevent network

flooding, and transmitted to the Bridge MCU. Example of these gestures are shown in figure 8

below.

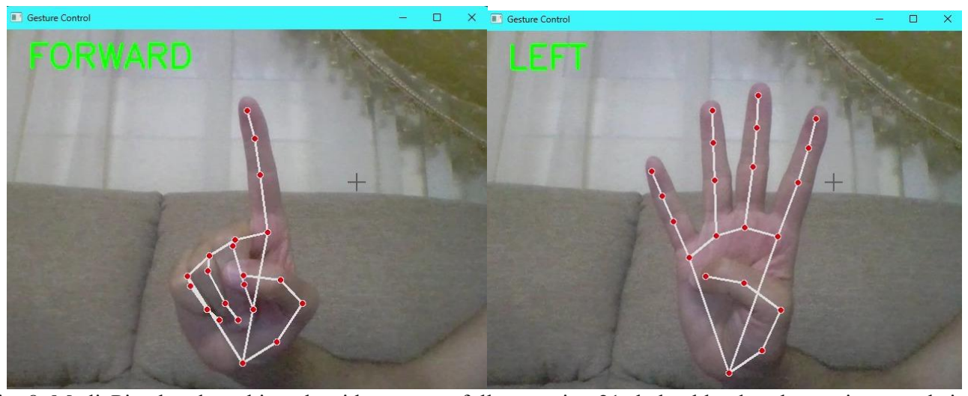
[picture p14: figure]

Fig. 8: MediaPipe hand-tracking algorithm successfully mapping 21 skeletal landmarks to trigger real-time directional kinematic commands (Forward and Left).

### VII. Ethical, Professional, and Societal Impact

A. Professional Code of Ethics

In the development of autonomous mechatronic systems, adherence to professional ethics is

crucial to ensure responsible and trustworthy engineering practices. This project strictly aligns

with the core principles of the IEEE Code of Ethics, particularly the mandate "to hold paramount

the safety, health, and welfare of the public" and "to disclose promptly factors that might endanger

the public or the environment." By applying these principles, the design process for Project

S.P.L.I.T. prioritized risk mitigation, transparent data handling, and fail-safe control mechanisms.

B. Ethical and Professional Issues in System Design

Designing a swarm of fast-moving, heavy robotic pendulums introduces several critical safety and

ethical considerations. First, the physical safety of human workers sharing the warehouse floor is

paramount. A software crash in the PID loop could result in the robot violently falling and acting

as a high-speed projectile. Second, the power system utilizes high-discharge Lithium Polymer

(LiPo) batteries. Without proper voltage protection, these cells pose a severe fire hazard. Finally,

from a data privacy standpoint, the implementation of overhead computer vision cameras

necessitates ethical data management to ensure that video feeds are processed locally and securely,

rather than transmitting sensitive employee footage to unsecured external servers.

C. Global, Economic, Environmental, and Societal Judgments

To address these ethical considerations, the engineering design was evaluated across four distinct

contexts:

- Global Impact: The inverted pendulum swarm architecture offers a highly scalable

framework for international supply chains. By standardizing this compact technology,

global logistics hubs can adopt higher-density storage solutions, significantly reducing the

land area required for new industrial facilities.

- Economic Impact: The system is designed to be highly cost-effective. By utilizing open-

source ESP32 microcontrollers, off-the-shelf L298N drivers, and 3D-printed chassis

components rather than proprietary industrial hardware, the economic barrier to entry is

drastically lowered. This allows Small and Medium Enterprises (SMEs) to implement

automated logistics without multi-million-dollar capital investments.

- Environmental Impact: To mitigate environmental harm, the robots are engineered for

low power consumption. Trading four wheels for two reduces the friction coefficient,

resulting in less electrical energy required for locomotion. However, the use of LiPo

batteries presents an E-waste challenge. To address this ethically, the design incorporates

a modular battery bay for safe extraction, and future iterations must prioritize the use of

readily recyclable battery chemistries and lead-free PCBs.

- Societal Impact: Societally, this robotic swarm benefits the workforce by removing

humans from ergonomically hazardous material-handling tasks. Furthermore, the intuitive

MediaPipe hand-gesture control ensures that the technology is highly accessible, allowing

operators of varying technical backgrounds to manage complex robotic fleets efficiently

and safely.

### VIII. Results & System Validation

The physical implementation of the distributed dual-MCU architecture successfully eliminated

network-induced processing pauses. By operating on an isolated Drive MCU, the 200 Hz cascaded

PID controller was able to continuously execute its calculations. Fused with the Kalman filter, the

system achieved near-zero pitch error, completely neutralizing high-frequency motor vibrations

and locking the robots in dynamic equilibrium. Furthermore, the dynamic gripping system proved

that a self-balancing inverted pendulum can maintain stability during abrupt center-of-mass shifts,

allowing the servo grippers to manipulate payloads flawlessly without tipping over. The telemetry

data was successfully transmitted in the web dashboard shown in figure 9 below, proved effective

in tuning the PID controllers and saving them to EEPROM on esp32 MCU.

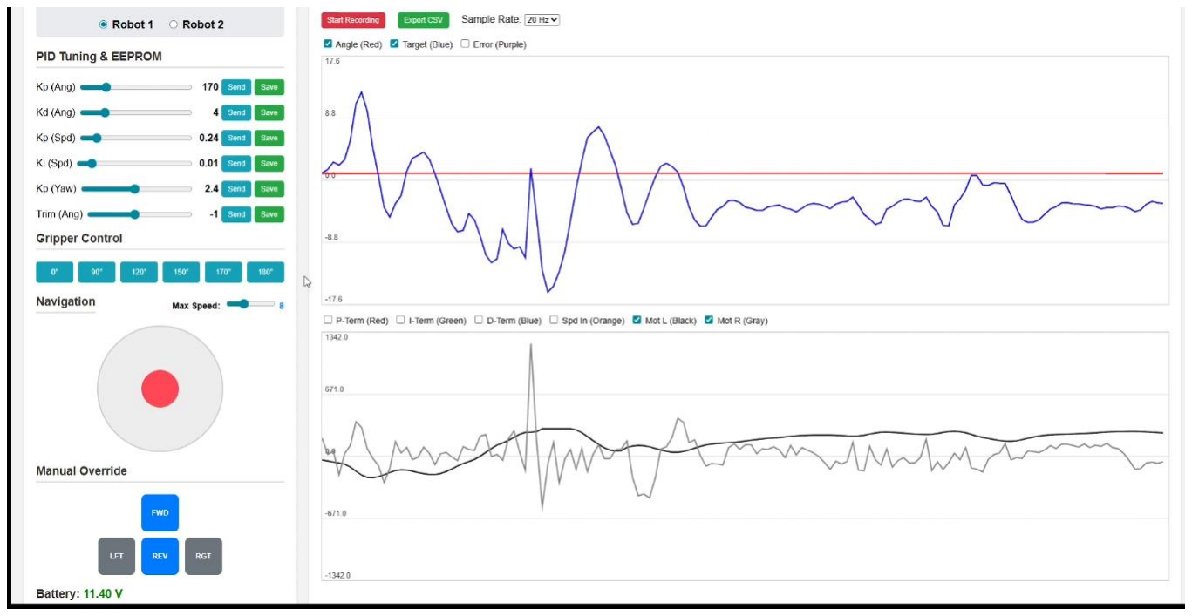
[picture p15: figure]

Fig. 9: dashboard and telemetry graphs rendering.

The communication topology proved highly robust under operational loads. The 500,000 baud

hardware UART serial connection successfully bridged the Cortex and Drive microcontrollers

without floating-point data corruption. Externally, the 2.4 GHz ESP-NOW protocol and

WebSockets connections delivered uninterrupted 20 frames-per-second telemetry to the graphical

dashboard, validating the theoretical electromagnetic wave models.

### IX. Conclusion

Project SPLIT successfully demonstrated that high-density logistics can be achieved without the

spatial penalties of traditional four-wheeled rovers. The deployment of a distributed hardware

architecture, paired with mathematically optimized sensor fusion and computer vision, yielded a

highly functional industrial prototype. Due to the rapid two-week prototyping timeframe, specific

engineering compromises were required. Future hardware iterations will replace the archaic

L298N motor drivers with highly efficient MOSFET-based alternatives or stepper motors to

provide the massive low-end torque needed for incline balancing. Additionally, custom-printed

circuit boards will be fabricated to eliminate jumper wire grounding issues that occasionally caused

the I2C bus to freeze. The ultimate goal for the swarm remains the implementation of the original

mechanical design, a system where two independent two-wheeled robots magnetically dock back-

to-back to form a heavy-lifting rover, and subsequently detach using a scissor mechanism to

perform distributed micro-deliveries.

### References

[1] H. Juang and K. Lum, Design and Control of a Two-Wheel Self-Balancing Robot using

the Arduino Microcontroller Board, 10th IEEE International Conference on Control and

Automation, 2013.

[2] O. Jamil, M. Jamil, Y. Ayaz, and K. Ahmad, Modeling, Control of a Two-Wheeled Self-

Balancing Robot, International Conference on Robotics and Emerging Allied Technologies

in Engineering, 2014.

[3] O. M. Mostafa et al., Mechatronics Project: Self-Balance Robot, Helwan University, 2023.
[4] J. Zhao, J. Li, and J. Zhou, Research on Two-Round Self-Balancing Robot SLAM Based

on the Gmapping Algorithm, Sensors, vol. 23, 2023.

[5] K. Nakamura, O. Sullivan, and E. Carmody, Development of a 4-DOF Serial Robotic

Manipulator for Pick-and-Place Applications, 2025.

[6] W. Harris et al., BiQu: Stair Climbing Robot Dog, Worcester Polytechnic Institute, 2025.
[7] F. T. Ulaby and U. Ravaioli, Fundamentals of Applied Electromagnetics, 8th ed. Pearson,

2020.

[8] Microprocessor & Microcontroller Course: Project Report Guidelines, EE 326 Guidelines.
[9] J. Fang, The LQR Controller Design of Two-Wheeled Self-Balancing Robot Based on the

Particle Swarm Optimization Algorithm, Mathematical Problems in Engineering, vol.

2014, 2014.

[10] L. Sun and J. Gan, Researching Of Two-Wheeled Self-Balancing Robot Base On LQR

Combined With PID, IEEE, 2010.

[11] H. Zhang and N. Mohamad Nor, Control Strategies for Two-Wheeled Self-Balancing

Robotic Systems: A Comprehensive Review, Robotics, vol. 14, 2025.

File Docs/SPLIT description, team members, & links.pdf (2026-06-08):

# S.P.L.I.T.: Snapping Pendulums Literally In Two

Designed and fully fabricated by engineering & AI students at the University of Prince Mugrin (UPM)

Modern warehouse facilities face a critical spatial challenge, as traditional four-wheeled logistics robots require massive floor space and wide aisles to maneuver safely. To solve this, a team of UPM engineering students fully designed, programmed, and constructed Project S.P.L.I.T., a highly advanced, self-balancing robotic swarm architecture.

By navigating purely on two wheels like an inverted pendulum using PID controllers, these robots maintain a drastically reduced physical footprint. This allows facilities to narrow their aisles and maximize high-density storage without sacrificing payload capacity.

Beyond mechanical stability, the UPM team successfully integrated advanced Artificial Intelligence and computer vision to manage the robotic swarm. The system currently features two distinct operational models to suit different industrial needs:

- Interactive Gesture Control: Using an overhead camera system, operators can drive and command the robot in real time using simple hand gestures. This creates a seamless, controller-free environment for human-robot collaboration.
- Autonomous Path Navigation: For fully automated environments, the robot utilizes a pre-planned pathfinding model, allowing it to autonomously navigate complex floor plans and execute logistics tasks without human intervention. This path-finding model makes use of surveillance cameras so that no overhead cost is added to the system by using existing essential systems for the purpose of navigation and control.

Project S.P.L.I.T. demonstrates the highest level of multidisciplinary engineering, seamlessly blending mechanical fabrication, complex control theory, and cutting-edge artificial intelligence into a functional, industry-ready prototype.

View this website portfolio for more information: https://abdelrahman-elawady.github.io/portfolio/projects/project_split.html (https://abdelrahman-elawady.github.io/portfolio/projects/project_split.html)

For full open-source documentation at GitHub: https://github.com/Abdelrahman-Elawady/SPLIT

Team members:

- Abdelrahman Elawady 4413746
- Ibrahim Albarbari 4410215
- Ghazi Alhartani 4311147
- Hassan Nasr 4410606

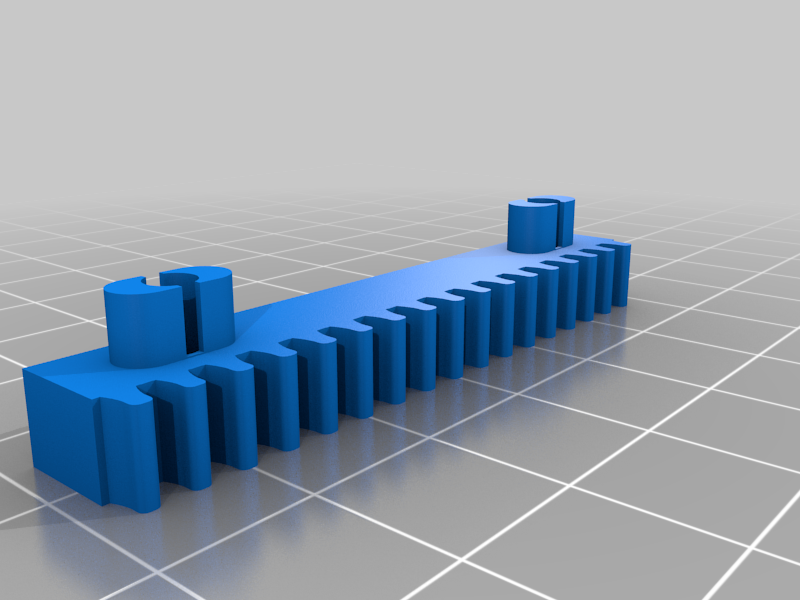
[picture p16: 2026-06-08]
Hardware/3D_models/Rack & Pinion Robotic Gripper Jaw - MG995/images/b4085dff65ca9222db2020aa29f92edd.png

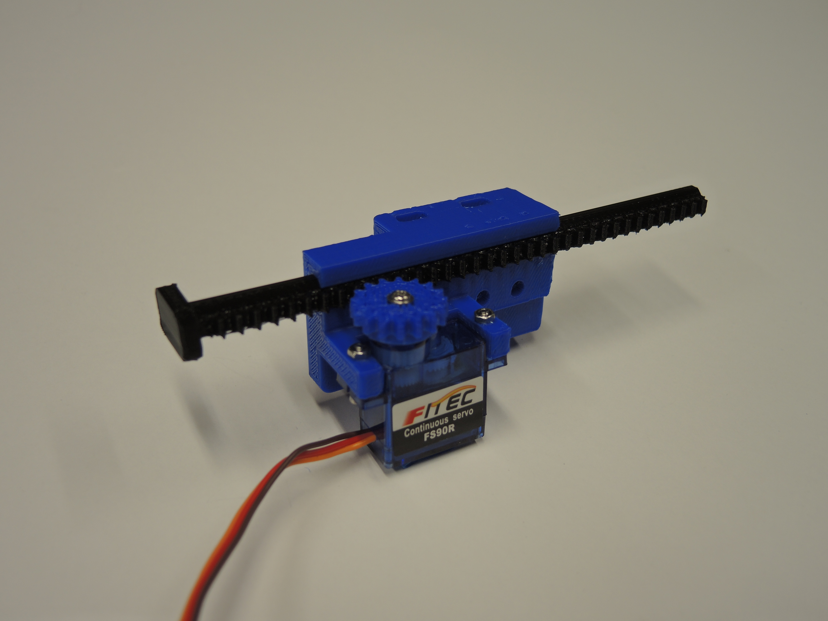
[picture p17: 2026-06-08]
Hardware/3D_models/Linear Servo Actuators - MG995/images/Mini_Iso_I.JPG

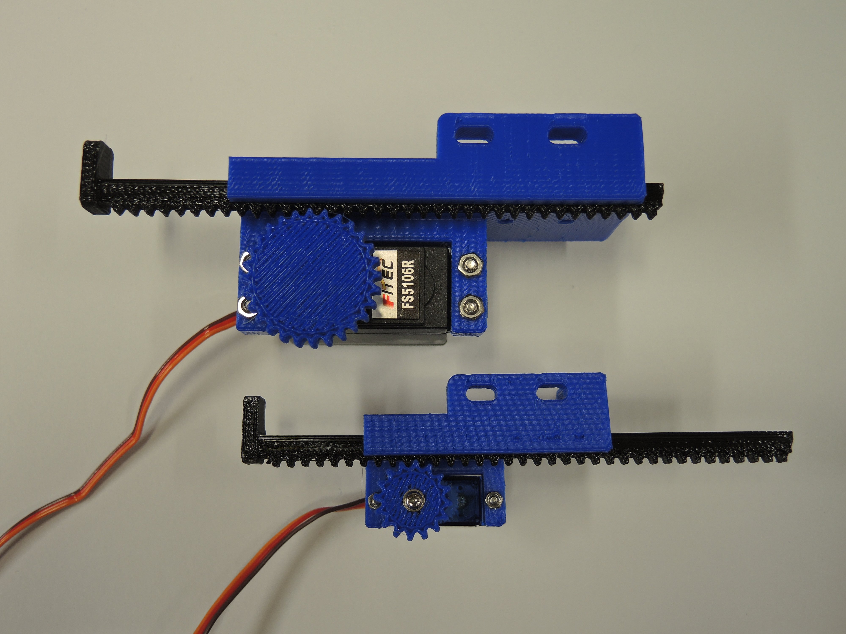
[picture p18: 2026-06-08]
Hardware/3D_models/Linear Servo Actuators - MG995/images/Both-_Top_View_Extended.JPG

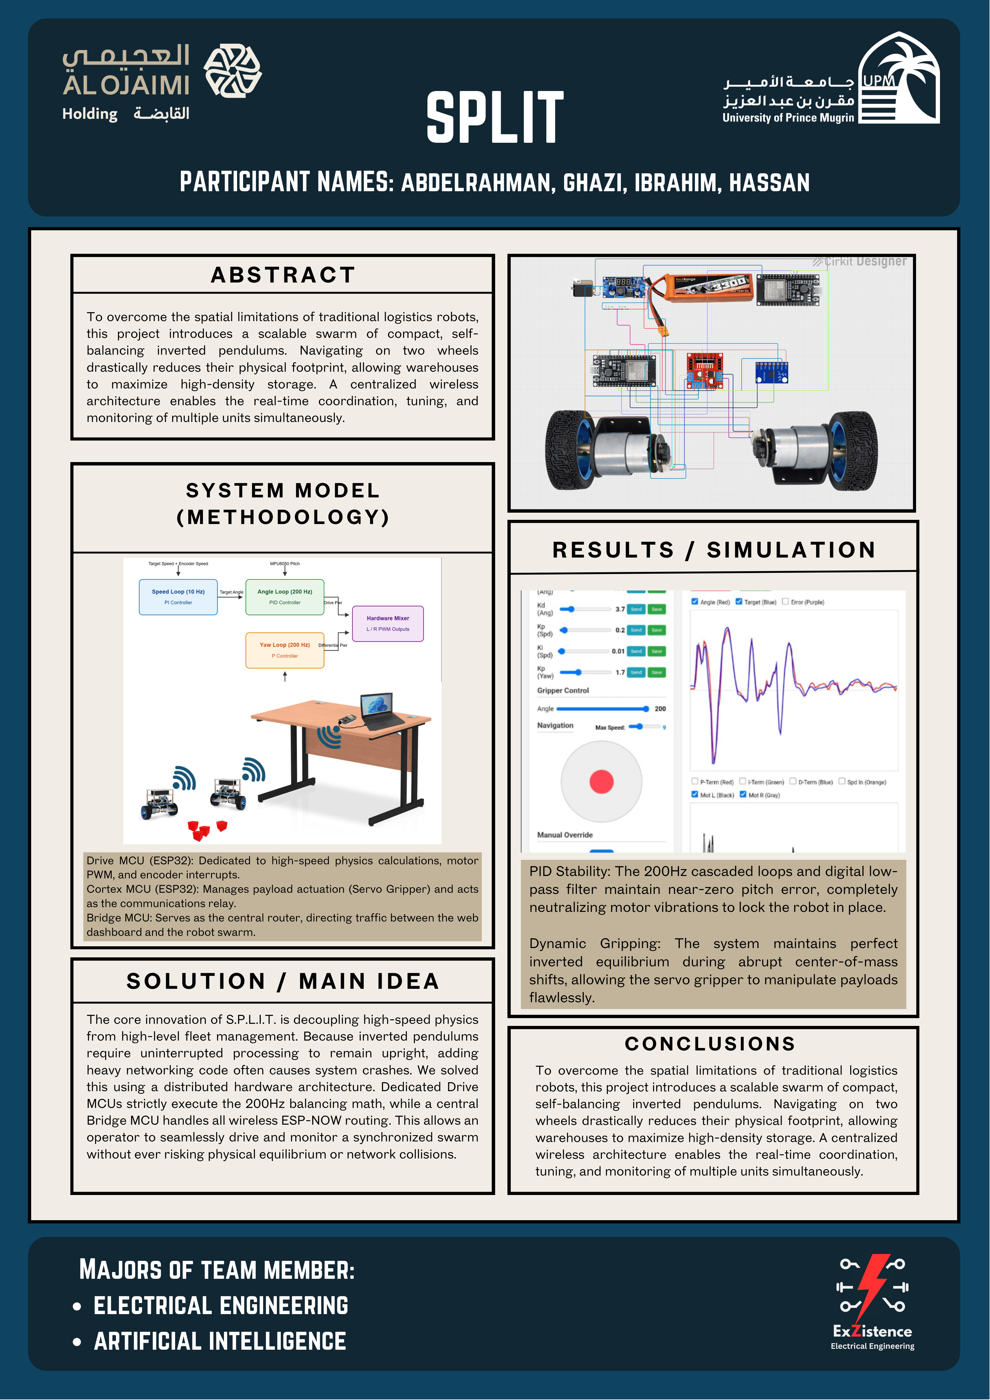
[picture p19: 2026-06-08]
Docs/poster.png

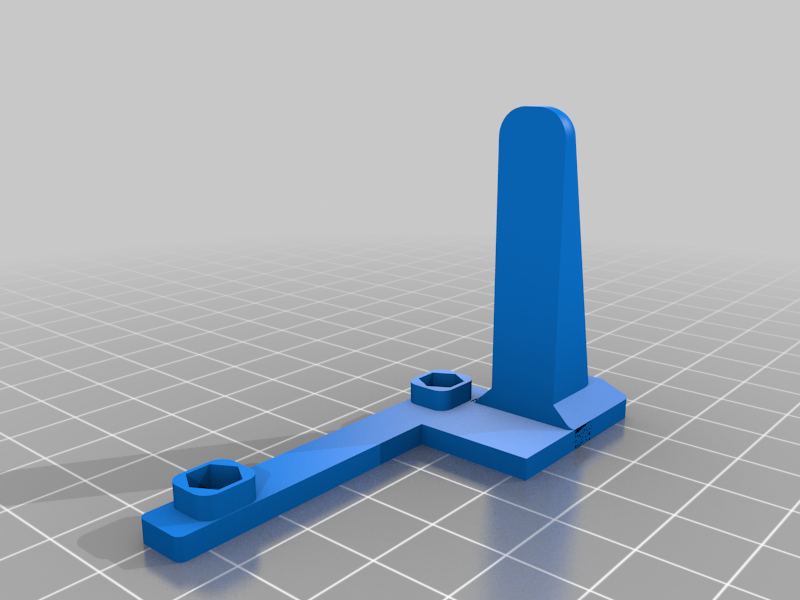
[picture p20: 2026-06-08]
Hardware/3D_models/Rack & Pinion Robotic Gripper Jaw - MG995/images/24f293e91af5c2380f0ab3b17aec9df3.png

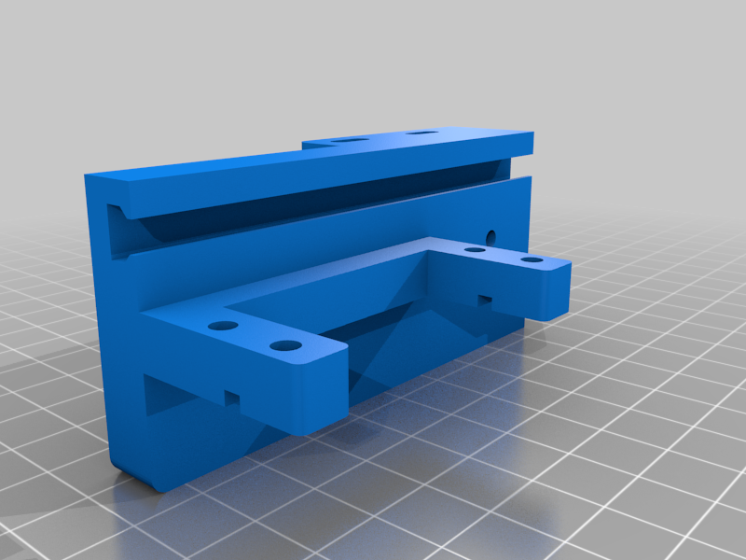
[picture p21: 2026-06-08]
Hardware/3D_models/Linear Servo Actuators - MG995/images/0ecc375ef6c08acbb51476853c850778.png

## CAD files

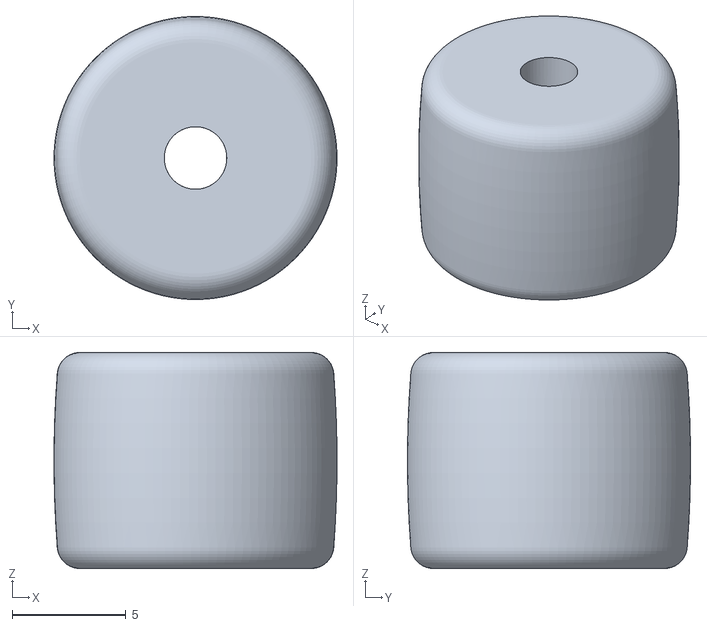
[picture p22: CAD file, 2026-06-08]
Hardware/3D_models/caster wheel/Wheel v2.stl
12.4 x 12.4 x 9.50

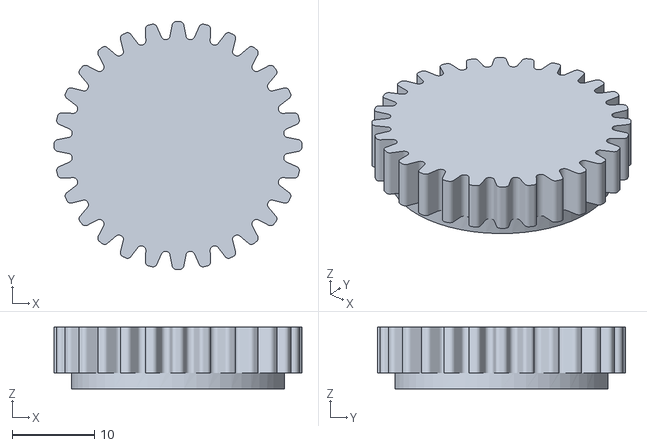
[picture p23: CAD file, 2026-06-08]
Hardware/3D_models/Linear Servo Actuators - MG995/files/Pinion_Gear_Large_Version.STL
30.2 x 30.2 x 7.51

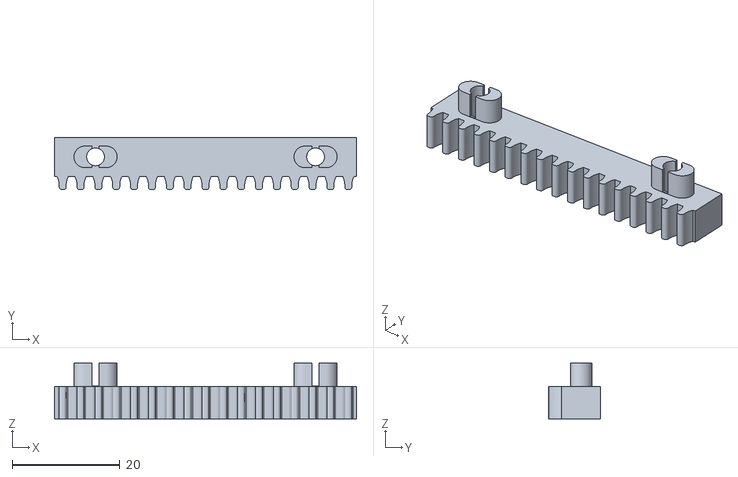
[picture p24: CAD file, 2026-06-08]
Hardware/3D_models/Rack & Pinion Robotic Gripper Jaw - MG995/files/Gripper_Rack.stl
56.0 x 9.70 x 10.3

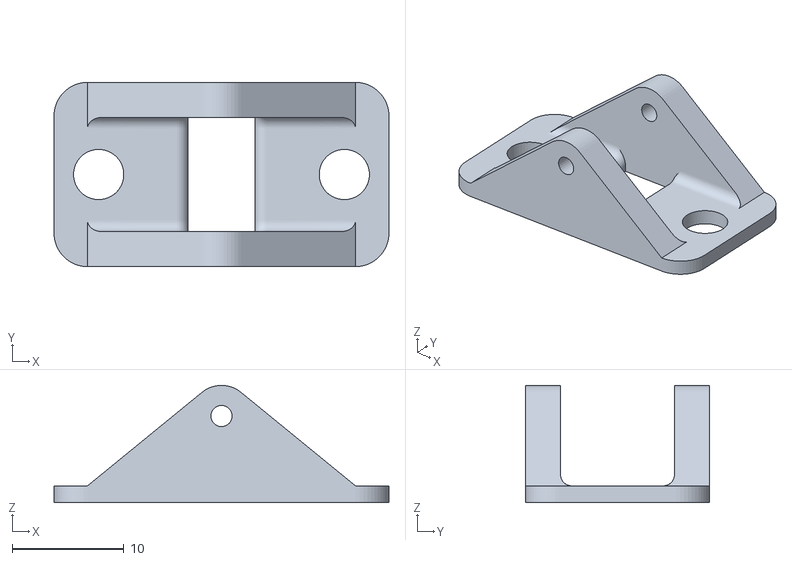
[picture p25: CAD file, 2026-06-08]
Hardware/3D_models/caster wheel/Frame.stl
30.0 x 16.5 x 10.5

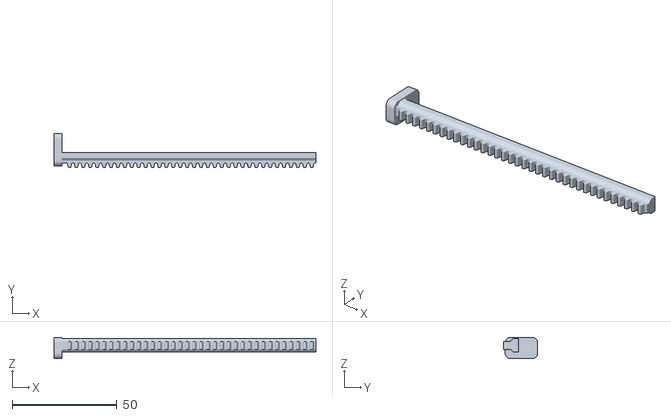
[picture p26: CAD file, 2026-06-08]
Hardware/3D_models/Linear Servo Actuators - MG995/files/Pusher_125mm_Long.STL
125.0 x 16.3 x 10.2

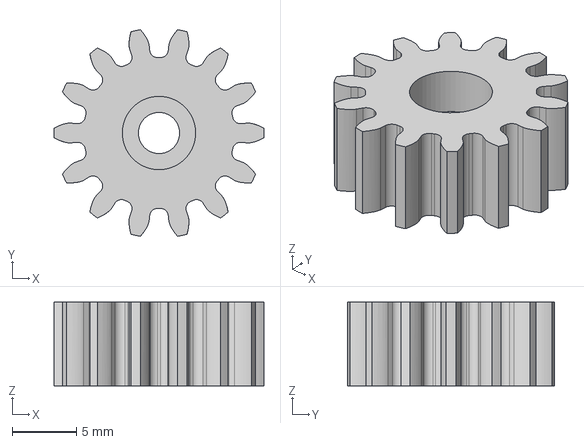
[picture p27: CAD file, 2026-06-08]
Hardware/3D_models/Rack & Pinion Robotic Gripper Jaw - MG995/files/SpurGear-14_teeth.step
16.3 x 16.1 x 6.50 mm

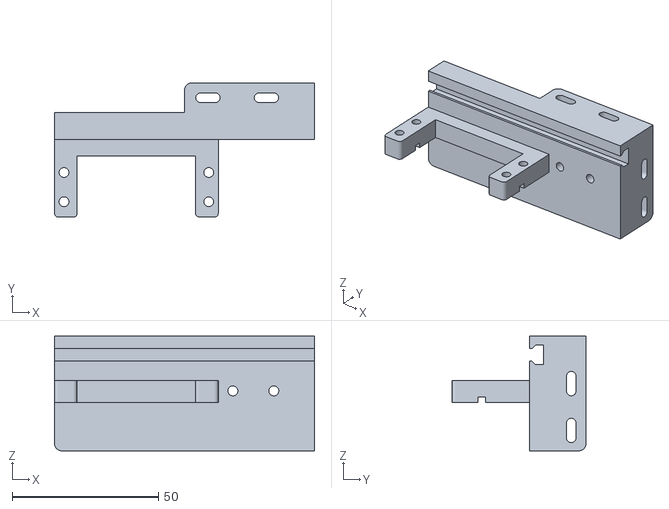
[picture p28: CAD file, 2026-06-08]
Hardware/3D_models/Linear Servo Actuators - MG995/files/Motor_Bracket_Large_Version.STL
88.9 x 45.9 x 39.2

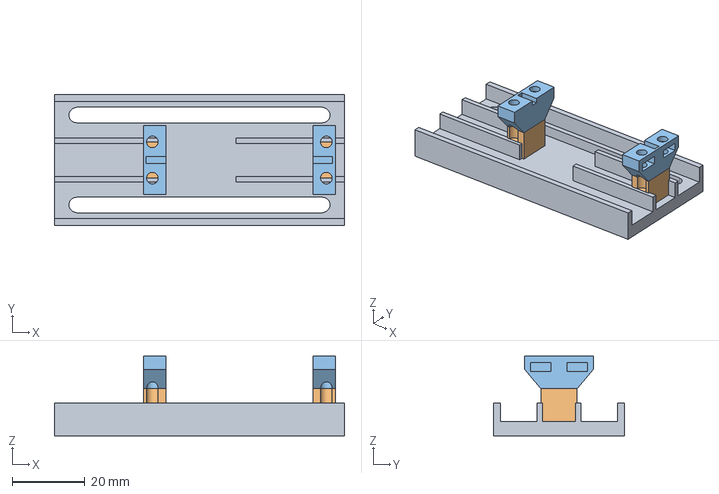
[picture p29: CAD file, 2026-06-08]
Hardware/3D_models/Rack & Pinion Robotic Gripper Jaw - MG995/files/Base.step
80.0 x 36.0 x 22.0 mm

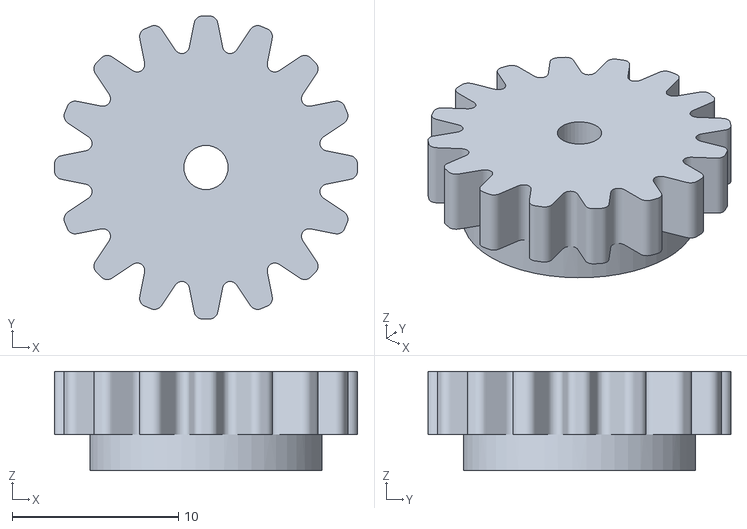
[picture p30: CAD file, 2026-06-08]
Hardware/3D_models/Linear Servo Actuators - MG995/files/Pinion_Gear_Mini_Version.STL
18.2 x 18.2 x 5.97

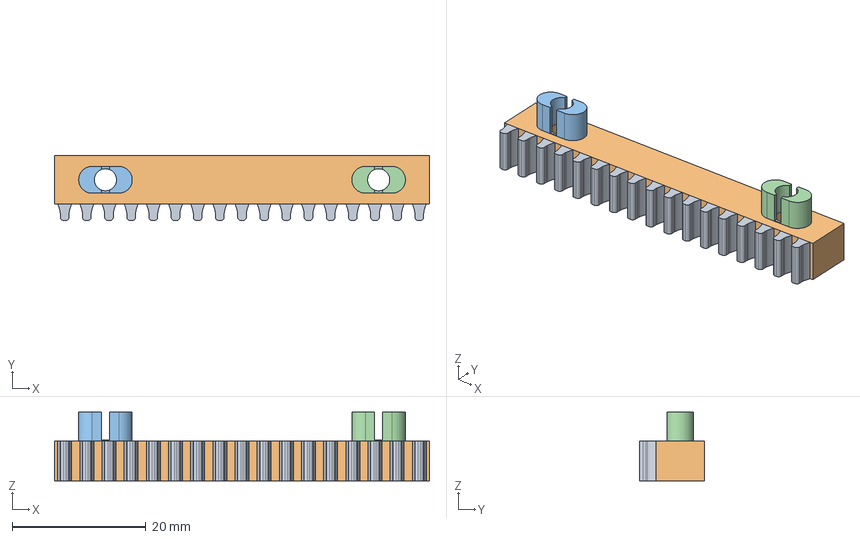
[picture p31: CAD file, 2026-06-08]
Hardware/3D_models/Rack & Pinion Robotic Gripper Jaw - MG995/files/Rack.step
56.0 x 9.70 x 10.3 mm

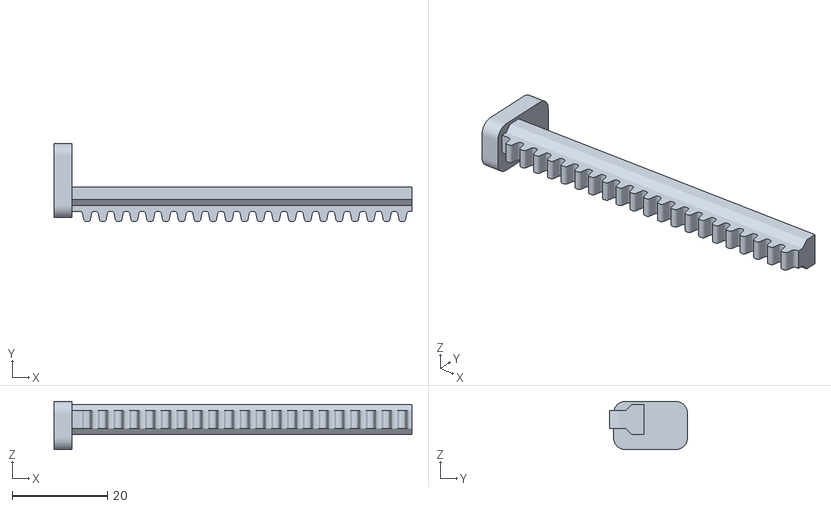
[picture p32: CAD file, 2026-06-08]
Hardware/3D_models/Linear Servo Actuators - MG995/files/Pusher_75mm_Long.STL
75.0 x 16.3 x 10.2

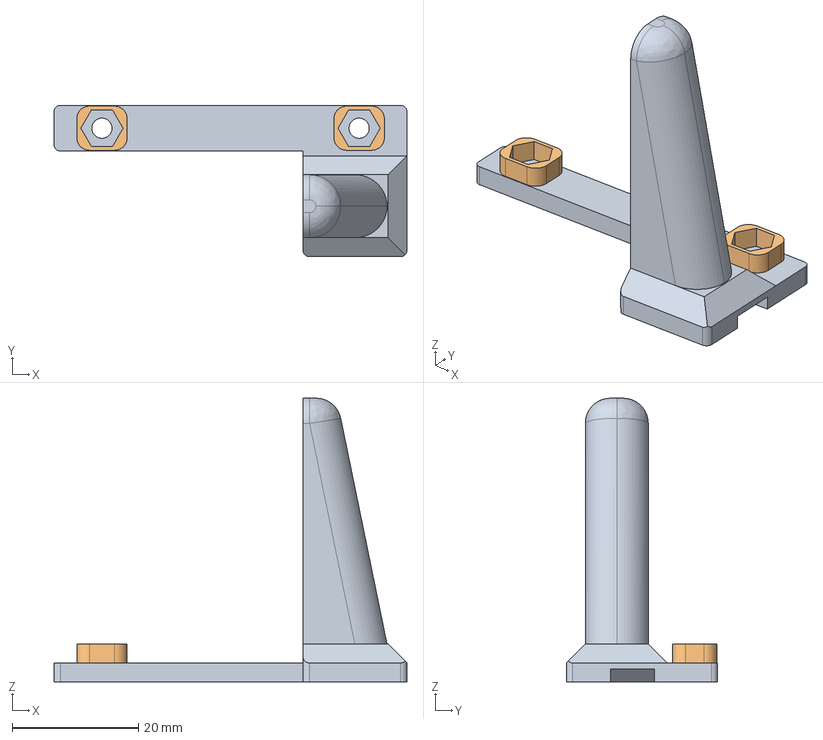
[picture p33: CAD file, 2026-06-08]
Hardware/3D_models/Rack & Pinion Robotic Gripper Jaw - MG995/files/Jaw.step
56.0 x 24.0 x 45.0 mm

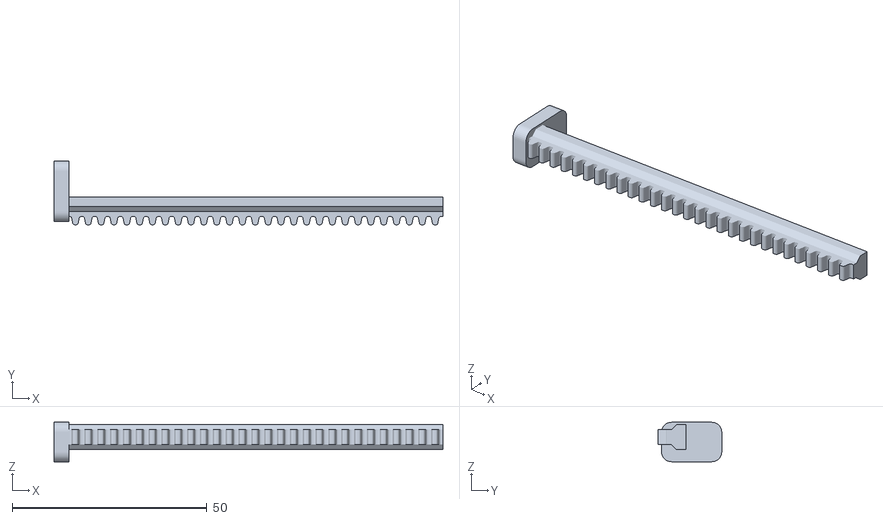
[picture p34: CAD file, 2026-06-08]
Hardware/3D_models/Linear Servo Actuators - MG995/files/Pusher_100mm_Long.STL
100.0 x 16.3 x 10.2

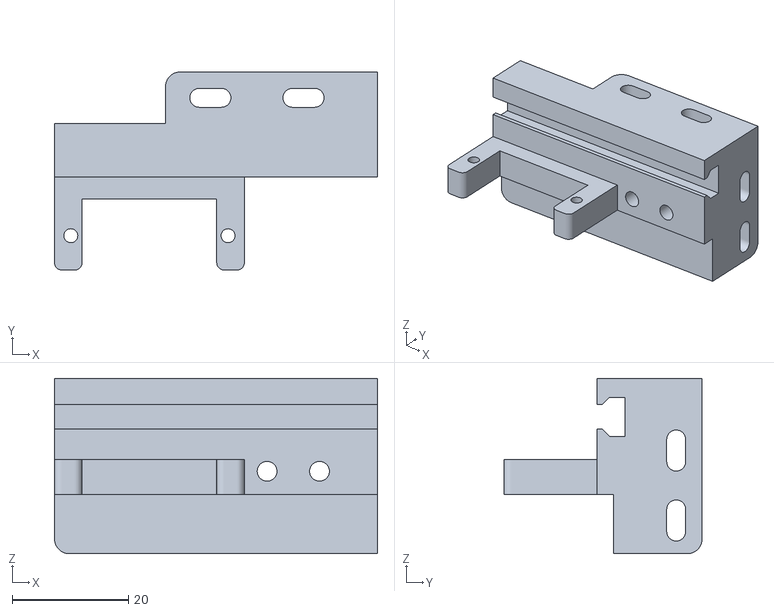
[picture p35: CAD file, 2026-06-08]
Hardware/3D_models/Linear Servo Actuators - MG995/files/Motor_Bracket_Mini_Version.STL
55.5 x 34.0 x 30.1

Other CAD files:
Hardware/3D_models/Rack & Pinion Robotic Gripper Jaw - MG995/files/Gripper_Pinion.stl
Hardware/3D_models/Rack & Pinion Robotic Gripper Jaw - MG995/files/Gripper_Jaw.stl
Hardware/3D_models/Linear Servo Actuators - MG995/files/Pusher_150mm_Long.STL
Hardware/3D_models/Rack & Pinion Robotic Gripper Jaw - MG995/files/Jaw22-70.step
Hardware/3D_models/Rack & Pinion Robotic Gripper Jaw - MG995/files/Gripper_Base.stl
Hardware/3D_models/Rack & Pinion Robotic Gripper Jaw - MG995/files/Jaw22-70.stl
Hardware/3D_models/Rack & Pinion Robotic Gripper Jaw - MG995/files/RP_Gripper_MK4_v10.f3d

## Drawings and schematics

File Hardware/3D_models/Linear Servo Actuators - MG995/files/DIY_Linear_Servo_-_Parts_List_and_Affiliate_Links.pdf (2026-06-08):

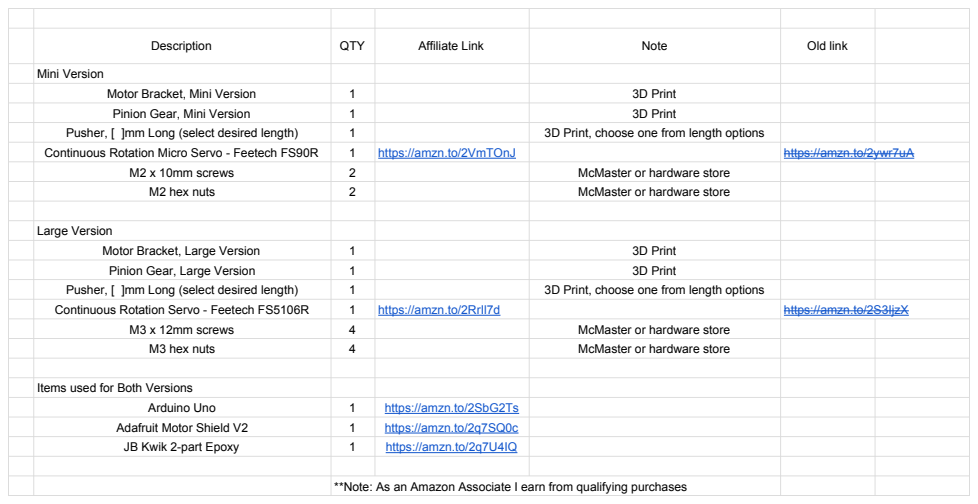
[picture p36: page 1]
Description; QTY; Affiliate Link; Note; Old link; Mini Version; Motor Bracket, Mini Version; 3D Print; Pinion Gear, Mini Version; Pusher, [ ]mm Long (select desired length); 3D Print, choose one from length options; Continuous Rotation Micro Servo - Feetech FS90R; https://amzn.to/2VmTOnJ; https://amzn.to/2ywr7uA; M2 x 10mm screws; McMaster or hardware store; M2 hex nuts; Large Version; Motor Bracket, Large Version; Pinion Gear, Large Version; Continuous Rotation Servo - Feetech FS5106R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

Items used for Both Versions

**Note: As an Amazon Associate I earn from qualifying purchases

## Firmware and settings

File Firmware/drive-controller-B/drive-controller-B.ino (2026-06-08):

#include <Arduino.h>     // for basic Arduino functions and types on platformio
#include <WiFi.h>        // for disabling WiFi on the physics chip and freeing up pins for I2C
#include <MPU6050.h>     // IMU sensor library installed from https://github.com/jrowberg/i2cdevlib & also available as a PlatformIO library
#include <Wire.h>        // for I2C communication with MPU6050
#include <Preferences.h> // The modern ESP32 replacement for EEPROM

Preferences preferences; // Create a Preferences object to handle non-volatile storage of PID parameters

const int BATTERY_PIN = 36; // ADC pin for battery voltage monitoring
int robot_state = 0;        // Hardware Safety Switch: 0 = Fallen, 1 = Balancing

MPU6050 mpu;                    // Create an MPU6050 object for interfacing with the IMU sensor
int16_t ax, ay, az, gx, gy, gz; // Variables to hold raw sensor data from the MPU6050
// here we chose to not use the dmp features of the MPU6050, as they can introduce additional latency and complexity that may not be ideal for a high-speed balancing robot.
// Instead, we will read the raw accelerometer and gyroscope data directly and implement our own sensor fusion algorithm (like a Kalman filter) to estimate the robot's angle
// and angular velocity. This approach allows for more control over the data processing and can be optimized for our specific use case & the use of the much powerful esp32 controller.

//  ================= HARDWARE PINS =================
// Motor Driver Pins
const int ENA = 25;
const int IN1 = 27;
const int IN2 = 14;
const int IN3 = 18;
const int IN4 = 13;
const int ENB = 26;
const int freq = 5000;    // PWM frequency for motor control - 5k to 10k is good
const int resolution = 8; // PWM resolution (8 bits = 0-255)

// Encoder Pins
const int ENC_L_A = 34;
const int ENC_L_B = 35;
const int ENC_R_A = 32;
const int ENC_R_B = 33;
// Volatile variables to hold encoder counts, updated in the ISR (Interrupt Service Routine) for accurate speed measurement without blocking the main loop
// Using interrupts allows us to capture every encoder pulse even at high speeds, which is crucial for precise control of the balancing robot.
volatile long count_left = 0;  
volatile long count_right = 0; 

void IRAM_ATTR isr_left() // Interrupt Service Routine for the left encoder, marked with IRAM_ATTR to ensure it runs from IRAM for faster execution
{ // This logic determines the direction of rotation based on the state of the encoder channels. 
  //If both channels are the same, we consider it as forward rotation and increment the count; otherwise, it's reverse rotation and we decrement the count.
  if (digitalRead(ENC_L_A) == digitalRead(ENC_L_B)) 
    count_left++;
  else
    count_left--;
}
void IRAM_ATTR isr_right()
{
  if (digitalRead(ENC_R_A) == digitalRead(ENC_R_B))
    count_right--;
  else
    count_right++;
}

// ================= TIMING & KALMAN FILTER =================
unsigned long last_time = 0; // Variable to keep track of the last time we read the sensors and updated the control loop, used for calculating delta time (dt) for the Kalman filter and PID calculations
unsigned long last_speed_time = 0; // Variable to track the last time we calculated the speed from the encoders, allowing us to run the speed control loop at a fixed interval (e.g., every 100 ms) independent of the main loop frequency
unsigned long last_telem_time = 0; // Variable to track the last time we sent telemetry data, allowing us to send updates at a fixed interval (e.g., every 100 ms) without overwhelming the communication channel
double dt = 0.005; // Initial guess for delta time (dt) between sensor readings, will be updated in the loop based on actual timing to ensure accurate calculations in the Kalman filter and PID controller, especially important if the loop execution time varies due to processing load or other factors.
unsigned long last_cmd_time = 0; // Tracks the last time a command arrived

float angle = 0, angle_speed = 0, q_bias = 0; // Variables for the Kalman filter: 'angle' is the estimated angle of the robot, 'angle_speed' is the estimated angular velocity, and 'q_bias' is the estimated bias in the gyroscope readings. The Kalman filter will
float P[2][2] = {{1, 0}, {0, 1}}; // Error covariance matrix for the Kalman filter, initialized to identity matrix. This matrix will be updated in the Kalman filter algorithm to reflect the uncertainty in our angle and bias estimates, allowing the filter to optimally combine the accelerometer and gyroscope data for accurate angle estimation.
float Q_angle = 0.001, Q_gyro = 0.003, R_angle = 0.5; // Kalman filter tuning parameters: Q_angle is the process noise variance for the angle, Q_gyro is the process noise variance for the gyroscope bias, and R_angle is the measurement noise variance for the angle. 
//These values can be adjusted to improve the performance of the Kalman filter based on the characteristics of the sensors and the dynamics of the robot.

// ================= PID VARIABLES =================
float Kp_ang, Kd_ang, Ki_ang = 0.0; // inner (angle) loop PID variables, running at 200 hz.
float angle_target = 0.0, angle_integral = 0.0; // 'angle_target' is the desired angle we want the robot to maintain (usually around 0 degrees for upright balancing), and 'angle_integral' is the accumulated integral of the angle error over time, used in the integral term of the PID controller to help correct for any steady-state error in the angle control loop.
float base_angle = 0.0; // 'base_angle' is an adjustable offset that can be used to set the robot's neutral position.
// float joy_fwd = 0.0; // 'joy_fwd' is a variable that can be used to add a forward or backward bias to the angle target based on joystick input.
float joy_target = 0.0;
float joy_current = 0.0;
float slew_rate = 0.02; // How fast it accelerates. Smaller = smoother.

float Kp_spd, Ki_spd; //middle (sped) loop PID variables, running at 10 hz.
float speed_filter = 0, speed_filter_old = 0, position_error = 0;
float speed_output = 0.0;

float Kp_yaw, Kd_yaw = 0.0, yaw_target = 0.0; // outer (yaw) loop running at the same time as the inner (angle) loop (200 hz), since it is reading instantaneous gyro for balancing.

// ================= TELEMETRY STRUCTURE =================
// Define a structure to hold all the telemetry data we want to send back to the campanion MCU that handles the wireless esp32-now communication with the remote controller.
typedef struct
{
  float ang;
  float targ;
  float err;
  float p_term;
  float i_term;
  float d_term;
  float spd_in;
  float pos_err;
  float mot_l;
  float mot_r;
  float bat;
  float kp_a;
  float kd_a;
  float kp_s;
  float ki_s;
  float kp_y;
  float base_ang;
} TelemetryData; 
TelemetryData telem; 

// ================= DUAL-MODE UART PARSER =================
String UART_Buffer = ""; 
void parseUART() // This function reads incoming data from Serial2, which is connected to the companion MCU.
{
  while (Serial2.available())
  {
    char c = Serial2.read();
    if (c == '\n')
    {
      if (UART_Buffer.length() >= 2) // We expect at least 2 characters for a valid command (e.g., "P:1.5" or "EX:1.5")
      {
        char prefix = UART_Buffer[0]; 

        // --- MODE 1: SAVE TO FLASH MEMORY (EEPROM) ---
        if (prefix == 'E')
        {
          char param = UART_Buffer[1];                    // Get the actual parameter letter
          float val = UART_Buffer.substring(3).toFloat(); // Skip "EX:"

          if (param == 'P')
          {
            Kp_ang = val;
            preferences.putFloat("Kp_ang", val);
          }
          else if (param == 'D')
          {
            Kd_ang = val;
            preferences.putFloat("Kd_ang", val);
          }
          else if (param == 'V')
          {
            Kp_spd = val;
            preferences.putFloat("Kp_spd", val);
          }
          else if (param == 'U')
          {
            Ki_spd = val;
            preferences.putFloat("Ki_spd", val);
          }
          else if (param == 'Y')
          {
            Kp_yaw = val;
            preferences.putFloat("Kp_yaw", val);
          }
          else if (param == 'O')
          {
            base_angle = val;
            preferences.putFloat("base_angle", val);
          }
        }
        // --- MODE 2: TEMPORARY RAM TUNING & JOYSTICK ---
        else
        {
          float val = UART_Buffer.substring(2).toFloat(); // Skip "X:"

          if (prefix == 'P')
            Kp_ang = val;
          else if (prefix == 'D')
            Kd_ang = val;
          else if (prefix == 'V')
            Kp_spd = val;
          else if (prefix == 'U')
            Ki_spd = val;
          else if (prefix == 'Y')
            Kp_yaw = val;
          else if (prefix == 'B') 
            {
            joy_target = val; // Store the requested speed here, do not apply it directly
            last_cmd_time = millis(); // Reset the safety timer!
            }
          else if (prefix == 'O')
            base_angle = val;
          else if (prefix == 'T') 
            {
            yaw_target = val;
          last_cmd_time = millis(); // Reset the safety timer!
            }
        }
      }
      UART_Buffer = "";
    }
    else
    {
      UART_Buffer += c;
    }
  }
}

float readBatteryVoltage() 
{
  // Read the raw ADC value from the battery voltage divider.
  int raw_adc = analogRead(BATTERY_PIN);
  float pin_voltage = (raw_adc / 4095.0) * 3.3;
  return pin_voltage * 6.01; //(1970+ 9870) / 1970 voltage divider ratio
}

// --- Function Prototypes ---
void driveMotors(float speed_left, float speed_right);
void updateKalman(float angle_m, float gyro_m);

void setup()
{
  UART_Buffer.reserve(64); // Pre-allocate 64 bytes of RAM for the UART string
  //Serial.begin(115200);
  WiFi.mode(WIFI_OFF); // Disable radio on the physics chip 
  // This frees up the pins used for WiFi (GPIO 21 and 22) for I2C communication with the MPU6050 IMU sensor, and also reduces power consumption and potential interference from the WiFi radio, which is beneficial for a real-time control application like a balancing robot.
  Serial2.begin(500000, SERIAL_8N1, 16, 17); 


  // Initialize Preferences and load saved values (or defaults if first time)
  preferences.begin("pid_tune", false); // "pid_tune" is the namespace for our stored preferences, and 'false' means we want read/write access (not read-only).
  Kp_ang = preferences.getFloat("Kp_ang", 0.0);
  Kd_ang = preferences.getFloat("Kd_ang", 0.0);
  Kp_spd = preferences.getFloat("Kp_spd", 0.0);
  Ki_spd = preferences.getFloat("Ki_spd", 0.0);
  Kp_yaw = preferences.getFloat("Kp_yaw", 0.0);
  base_angle = preferences.getFloat("base_angle", 0.0);

  pinMode(IN1, OUTPUT);
  pinMode(IN2, OUTPUT);
  pinMode(IN3, OUTPUT);
  pinMode(IN4, OUTPUT);

  // PlatformIO Version 2 LEDC Setup
  // ledcSetup(0, freq, resolution); 
  // ledcSetup(1, freq, resolution);
  // ledcAttachPin(ENA, 0);
  // ledcAttachPin(ENB, 1);

  ledcAttach(ENA, freq, resolution);
  ledcAttach(ENB, freq, resolution);

  pinMode(ENC_L_A, INPUT);
  pinMode(ENC_L_B, INPUT);
  pinMode(ENC_R_A, INPUT);
  pinMode(ENC_R_B, INPUT);
  attachInterrupt(digitalPinToInterrupt(ENC_L_A), isr_left, RISING);
  attachInterrupt(digitalPinToInterrupt(ENC_R_A), isr_right, RISING);
  pinMode(BATTERY_PIN, INPUT);

  Wire.begin(21, 22); 
  Wire.setClock(400000); //set I2C clock to 400 khz.
  Wire.setTimeOut(10); //prevent I2C bus lockup by setting a timeout for I2C transactions. If a transaction takes longer than 10 ms, it will be aborted and the bus will be released, allowing the robot to recover from potential communication issues with the MPU6050 sensor without freezing the entire system.
  mpu.initialize(); // Initialize the MPU6050 sensor

  // Manually set the accelerometer and gyroscope offsets via calibration script.
  //6329	4760	9055	-219	-209	13
  mpu.setXAccelOffset(6329); 
  mpu.setYAccelOffset(4760);
  mpu.setZAccelOffset(9055);
  mpu.setXGyroOffset(-219);
  mpu.setYGyroOffset(-209);
  mpu.setZGyroOffset(13);

  last_time = micros(); 
  last_speed_time = millis(); 
}

void loop()
{
  parseUART(); 
  
  unsigned long current_time = micros();
  dt = (current_time - last_time) / 1000000.0; //we convert microseconds to seconds for the dt variable used in the Kalman filter and PID calculations. 
  last_time = current_time;
  if (dt > 0.1) 
    dt = 0.005; 

  mpu.getMotion6(&ax, &ay, &az, &gx, &gy, &gz);
  // In the real world, gravity ensures these 6 axes will NEVER all be exactly zero at the same time.
  // If they are all 0, the I2C wire is disconnected or the MPU6050 has crashed.
  if (ax == 0 && ay == 0 && az == 0 && gx == 0 && gy == 0 && gz == 0) {
    robot_state = 0;      // Immediately kill the physics loop
    driveMotors(0, 0);    // Hard stop the motors
    return;               // Skip the rest of the loop until the sensor comes back online
  }
  float angle_m = atan2(ax, az) * (180 / PI); 
  float gyro_y = -gy / 131.0; // -ve sign to align gyro direction with angle direction, and divide by sensitivity scale factor (131 LSB/°/s for the default ±250 °/s range) to convert raw gyro reading to degrees per second.
  updateKalman(angle_m, gyro_y);

  //diagnosis:
  // Serial.print("Angle: "); 
  // Serial.println(angle);

  if (robot_state == 0) 
  {
    driveMotors(0, 0);
    angle_integral = 0; // prevent windup
    position_error = 0;
    count_left = 0;
    count_right = 0;
    speed_filter = 0;
    speed_filter_old = 0;

    if (angle > -20 && angle < 20) // If the robot is within a reasonable angle range (not too far fallen), we can allow it to start balancing again when it detects movement. This helps prevent the robot from trying to balance when it's completely tipped over, which could lead to erratic behavior or damage.    
    {
      robot_state = 1;
      last_speed_time = millis();
    }
  }
  else if (robot_state == 1)
  {
    if (angle > 45 || angle < -45) // protection when fallen
    {
      robot_state = 0;
      return;
    }

    // ==========================================
    // THE DEADMAN'S SWITCH (500ms Timeout)
    // ==========================================
    if (millis() - last_cmd_time > 500) 
    {
      joy_target = 0.0;
      yaw_target = 0.0;
    }

    // ==========================================
    // 10 HZ SPEED LOOP (Runs every 100ms)
    // ==========================================
    if (millis() - last_speed_time >= 100) 
    {
      long left_pulse = count_left; 
      long right_pulse = count_right;
      count_left = 0;
      count_right = 0;

      float current_speed = (left_pulse + right_pulse) / 2.0; 
      speed_filter = (speed_filter_old * 0.4) + (current_speed * 0.6); 
      speed_filter_old = speed_filter;

      // USE joy_target INSTEAD OF joy_fwd
      if (joy_target == 0.0 && yaw_target == 0.0)
        position_error += speed_filter;
      else
        position_error = 0;
      
      if (position_error > 300) position_error = 300;
      if (position_error < -300) position_error = -300;

      speed_output = (Kp_spd * speed_filter) + (Ki_spd * position_error); 
      if (speed_output > 15) speed_output = 15;
      else if (speed_output < -15) speed_output = -15;

      last_speed_time = millis();
    } // <-- END OF 10HZ LOOP

    // ==========================================
    // 200 HZ FAST LOOP (Runs every 5ms)
    // ==========================================
    
    // 1. The Trajectory Smoother (Executes rapidly for butter-smooth acceleration)
    if (joy_current < joy_target) {
      joy_current += slew_rate;
      if (joy_current > joy_target) joy_current = joy_target;
    } else if (joy_current > joy_target) {
      joy_current -= slew_rate;
      if (joy_current < joy_target) joy_current = joy_target;
    }

    // 2. Combine the targets
    angle_target = base_angle - speed_output - joy_current;

    // 3. Standard PID Math
    float current_error = angle - angle_target;
    //angle_integral += current_error * dt;

    // Only accumulate the integral if we are NOT forcefully driving via joystick
    if (joy_target == 0.0) {
      angle_integral += current_error * dt;
    } else {
      // Bleed off the accumulated integral quickly so it doesn't fight the joystick
      angle_integral *= 0.8; 
    }
    if (angle_integral > 300) angle_integral = 300;
    if (angle_integral < -300) angle_integral = -300;

    float p_out = Kp_ang * current_error;
    float i_out = Ki_ang * angle_integral;
    float d_out = Kd_ang * angle_speed;
    float motor_out = p_out + i_out + d_out;

    float gyro_z = gz / 131.0; 
    float yaw_error = yaw_target - gyro_z;
    float yaw_out = (Kp_yaw * yaw_error);

    float left_motor_final = motor_out - yaw_out;
    float right_motor_final = motor_out + yaw_out;

    driveMotors(left_motor_final, right_motor_final);

    if (millis() - last_telem_time > 100)
    {
      telem.ang = angle;
      telem.targ = angle_target;
      telem.err = current_error;
      telem.p_term = p_out;
      telem.i_term = (Ki_spd * position_error); //i_out;
      telem.d_term = d_out;
      telem.spd_in = speed_filter;
      telem.pos_err = position_error;
      telem.mot_l = left_motor_final;
      telem.mot_r = right_motor_final;
      telem.bat = readBatteryVoltage();

      // Attach the active PID values to the payload
      telem.kp_a = Kp_ang;
      telem.kd_a = Kd_ang;
      telem.kp_s = Kp_spd;
      telem.ki_s = Ki_spd;
      telem.kp_y = Kp_yaw;
      telem.base_ang = base_angle;
      
      Serial2.write(0xAA);
      Serial2.write(0xAA);

      Serial2.write((uint8_t *)&telem, sizeof(TelemetryData));
      last_telem_time = millis();
    }
  }
}

void driveMotors(float speed_left, float speed_right)
{ 
  if (speed_left > 255)
    speed_left = 255;
  else if (speed_left < -255)
    speed_left = -255;
  if (speed_right > 255)
    speed_right = 255;
  else if (speed_right < -255)
    speed_right = -255;
  // We set a minimum speed threshold to ensure the motors receive enough power to overcome static friction and start moving. ((deadband))
  if (abs(speed_left) < 45 && abs(speed_left) > 0)
    speed_left = (speed_left > 0) ? 45 : -45;
  if (abs(speed_right) < 45 && abs(speed_right) > 0)
    speed_right = (speed_right > 0) ? 45 : -45;

  if (speed_left > 0)
  {
    digitalWrite(IN1, HIGH);
    digitalWrite(IN2, LOW);
  }
  else if (speed_left < 0)
  {
    digitalWrite(IN1, LOW);
    digitalWrite(IN2, HIGH);
  }
  else
  {
    digitalWrite(IN1, LOW);
    digitalWrite(IN2, LOW);
  }

  if (speed_right > 0)
  {
    digitalWrite(IN3, HIGH);
    digitalWrite(IN4, LOW);
  }
  else if (speed_right < 0)
  {
    digitalWrite(IN3, LOW);
    digitalWrite(IN4, HIGH);
  }
  else
  {
    digitalWrite(IN3, LOW);
    digitalWrite(IN4, LOW);
  }

  // PlatformIO Version 2 PWM execution
  // ledcWrite(0, abs(speed_left));
  // ledcWrite(1, abs(speed_right));

  ledcWrite(ENA, abs(speed_left));
  ledcWrite(ENB, abs(speed_right));
}

void updateKalman(float angle_m, float gyro_m)
{
  // just a bunch of math :)
  angle += (gyro_m - q_bias) * dt; 
  float angle_err = angle_m - angle;
  P[0][0] += (Q_angle - P[0][1] - P[1][0]) * dt;
  P[0][1] -= P[1][1] * dt;
  P[1][0] -= P[1][1] * dt;
  P[1][1] += Q_gyro * dt;
  float S = R_angle + P[0][0];
  float K_0 = P[0][0] / S;
  float K_1 = P[1][0] / S;
  P[0][0] -= K_0 * P[0][0];
  P[0][1] -= K_0 * P[0][1];
  P[1][0] -= K_1 * P[0][0];
  P[1][1] -= K_1 * P[0][1];
  q_bias += K_1 * angle_err;
  angle_speed = gyro_m - q_bias;
  angle += K_0 * angle_err;
}

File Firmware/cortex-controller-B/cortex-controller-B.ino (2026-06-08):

#include <Arduino.h> // essential for platform io
#include <esp_now.h> 
#include <WiFi.h>
#include <ESP32Servo.h> //necessary for esp32 to use servos 

// ================= HARDWARE DEFINITIONS =================
const int SERVO_PIN = 4;
Servo gripper;

// ================= COMMUNICATIONS HUB =================
uint8_t bridgeAddress[] = {0x00, 0x00, 0x00, 0x00, 0x00, 0x00}; // MAC address of the bridge MCU's ESP-NOW interface, which we will send telemetry data to and receive commands from. then we forward these commands to the Drive MCU over Serial2, and send telemetry data back to the bridge MCU over ESP-NOW.
esp_now_peer_info_t peerInfo; 

typedef struct
{
  float ang;
  float targ;
  float err;
  float p_term;
  float i_term;
  float d_term;
  float spd_in;
  float pos_err;
  float mot_l;
  float mot_r;
  float bat;
  float kp_a;
  float kd_a;
  float kp_s;
  float ki_s;
  float kp_y;
  float base_ang;
} TelemetryData;
TelemetryData telem;

typedef struct
{
  char text[32];
} CommandMsg;
CommandMsg incomingCmd;

// ================= ESP-NOW RECEIVER =================
//void OnDataRecv(const uint8_t *mac_addr, const uint8_t *incomingData, int len)
void OnDataRecv(const esp_now_recv_info *recv_info, const uint8_t *incomingData, int len)
{
  const uint8_t *mac_addr = recv_info->src_addr;
  memcpy(&incomingCmd, incomingData, sizeof(incomingCmd));

  // Isolate and execute the servo logic directly on the Cortex
  if (incomingCmd.text[0] == 'G')
  {
    gripper.write(atoi(incomingCmd.text + 2));
  }
  // Forward all physics, joystick, and EEPROM commands to the Drive MCU
  else
  {
    Serial2.print(incomingCmd.text);
    Serial2.print('\n');
  }
}

void setup()
{
  //Serial.begin(115200);

  // Initialize the high-speed hardware UART link to the Drive MCU
  Serial2.begin(500000, SERIAL_8N1, 16, 17);

  // Initialize the Gripper Servo safely away from the physics timers
  ESP32PWM::allocateTimer(0);
  gripper.setPeriodHertz(50);
  gripper.attach(SERVO_PIN, 500, 2500); //mg995MG 500-2400us pulse width range

  // Initialize ESP-NOW on Channel 1
  WiFi.mode(WIFI_STA); // ESP-NOW requires WiFi to be in Station mode, but we won't actually connect to any WiFi network. This also frees up the WiFi hardware for ESP-NOW communication.
  WiFi.setSleep(false);
  esp_now_init();
  esp_now_register_recv_cb(OnDataRecv); // Register the receive callback function to handle incoming ESP-NOW messages.

  memcpy(peerInfo.peer_addr, bridgeAddress, 6); // memcpy is used to copy the MAC address of the Drive MCU into the peerInfo structure. 6 stands for the 6 bytes in a MAC address.
  peerInfo.channel = 1; // ESP-NOW operates on a specific WiFi channel. Both devices must be on the same channel to communicate. Channel 1 is a common choice, but you can choose any channel from 1 to 13 depending on your environment and potential interference.
  peerInfo.encrypt = false; // We are not using encryption for this simple telemetry and command exchange, but ESP-NOW does support encrypted communication if needed for security.
  peerInfo.ifidx = WIFI_IF_STA; // Specify that this peer is on the Station interface, which is the only interface available when WiFi is in Station mode.
  esp_now_add_peer(&peerInfo); // Add the Drive MCU as a peer so we can send telemetry data to it.
}

void loop()
{
  // Check if we have enough bytes for the header (2) + the payload
  while (Serial2.available() >= sizeof(TelemetryData) + 2) 
  {
    // Check if the first two bytes are our synchronization header
    if (Serial2.read() == 0xAA && Serial2.peek() == 0xAA) 
    {
      Serial2.read(); // Consume the second 0xAA byte
      
      // Now we know the next bytes are perfectly aligned!
      Serial2.readBytes((uint8_t *)&telem, sizeof(TelemetryData));
      esp_now_send(bridgeAddress, (uint8_t *)&telem, sizeof(TelemetryData));
    }
  }
}

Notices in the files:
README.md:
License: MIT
